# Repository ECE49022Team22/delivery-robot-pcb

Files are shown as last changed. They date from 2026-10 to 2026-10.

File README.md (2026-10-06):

# Delivery Robot PCB

KiCad design files for the ECE49022 Team 22 senior design delivery robot control board.

This repository is the shared workspace for the board schematic, PCB layout, project libraries and design documentation.

## System overview

The current schematic includes an STM32F091RC microcontroller core, programming/debug and UART headers, reset and boot circuitry, clock and decoupling components, test points, and power conversion from 12 V to 5 V and 3.3 V.

Motor-driver and IMU interfaces are part of the planned system and still need to be completed and reviewed in the board design.

## Getting started

1. Install KiCad 10 with its standard symbol and footprint libraries.
2. Clone this repository.
3. Open delivery_robot_1.kicad_pro in KiCad Manager.
4. Open delivery_robot_1.kicad_sch to view the complete schematic. Use the Schematic Hierarchy panel to navigate between sheets.

Custom symbol and footprint libraries are included and registered in the project library tables. Keep the directory structure intact so project-relative library paths resolve.

## Repository contents

| Path | Purpose |
| --- | --- |
| delivery_robot_1.kicad_pro | Active KiCad project settings |
| delivery_robot_1.kicad_sch | Main board schematic |
| LDO_3V3.kicad_sch | Hierarchical 3.3 V power supply sheet |
| libs/ | Custom buck converter symbols and footprints |
| LDO_KiCad/ | Reusable LDO example, libraries and footprint review |
| sym-lib-table, fp-lib-table | Project-specific library configuration |
| docs/ | Subsystem documentation and design notes |
| validation/ | Connectivity checks and reference netlist |
| system-ERC-report.txt | Saved electrical rules check results |
| system-netlist.xml | Exported system connectivity |
| system-preview/ | Rendered schematic sheets |
| received-project-settings/ | Archived initial settings; not the active project |

Power supply details are documented in [docs/power-supply.md](docs/power-supply.md). Earlier simulation notes are in [STM32-LDO-design.md](STM32-LDO-design.md).

Component-selection rationale is in [docs/passive-selection-review.md](docs/passive-selection-review.md), [docs/clock-selection.md](docs/clock-selection.md) and [docs/fuse-selection.md](docs/fuse-selection.md). The fuse selection includes both the PCB-mounted holder and its separately purchased insert.

## Design status

The project is in schematic development. No system PCB layout has been committed yet.

The saved ERC report from October 5, 2026 contains 7 errors and 55 warnings. Remaining work includes reviewing power connectivity and symbol definitions, completing peripheral interfaces, finalizing component values and footprints, and designing and checking the PCB layout.

Saved reports describe the checked revision. Regenerate them after relevant design changes.

## Team workflow

- Use the active delivery_robot_1 project for board work.
- Pull current changes before editing and coordinate ownership of schematic sheets and the PCB.
- Work on branches and review changes before merging.
- Save files in KiCad before committing. Include required project-local libraries with design changes.
- Run ERC after schematic changes and DRC after layout changes. Review outstanding findings before ordering boards.

Editing locks, local UI settings and automatic backups are excluded from Git. Edit the native KiCad sources directly; regenerating files from older scripts may overwrite manual changes.

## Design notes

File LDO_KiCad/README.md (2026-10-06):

# Reusable LDO schematic for KiCad

Created and verified with KiCad 10.0.6. All files are kept in this folder under Senior Design.

## Open and edit

Open this repository's LDO_KiCad/STM32_LDO.kicad_pro in KiCad Manager, then open STM32_LDO.kicad_sch and select LDO Power (page 2). The separately pinned original folder is not this repository copy.

The schematic was opened and saved through KiCad 10.0.6 on 2026-10-05 to apply its automatic format repair and conversion. ERC and the exported-netlist connection checks passed again after that save. Do not regenerate it from the original builder, which would overwrite these native editor saves.

Open **STM32_LDO.kicad_pro** in KiCad. Open its schematic, then enter the **LDO Power** hierarchical sheet. The circuit itself is **LDO_Power.kicad_sch**. The top sheet is an integration example with external-source PWR_FLAG symbols and an optional 3.3 V test point. The reusable child contains U1, R1/R2 and C1–C4 only.

The three sheet connections are:

| Sheet pin | Connect to |
|---|---|
| VIN_5V | Buck converter's regulated 5 V supply |
| VOUT_3V3 | STM32, IMU and other 3.3 V supply branches |
| GND | Common system ground |

No global power symbols are used in the child, so importing it will not silently merge rail names elsewhere. EN is tied to input for always-on operation. Both IN and OUT pins are wired; ground pin 4 and exposed pad 9 are grounded.

## Import into your teammates' system schematic

1. Copy `LDO_Power.kicad_sch`, `LDO_Power.kicad_sym` and the `LDO_Power.pretty` folder into their project folder. Keep their existing project and library tables.
2. In **Preferences → Manage Symbol Libraries → Project Specific Libraries**, add `LDO_Power.kicad_sym` with nickname `LDO_Power`. Use `${KIPRJMOD}/LDO_Power.kicad_sym` as its path.
3. In **Preferences → Manage Footprint Libraries → Project Specific Libraries**, add the `LDO_Power.pretty` folder with nickname `LDO_Power`. Use `${KIPRJMOD}/LDO_Power.pretty`.
4. In the system schematic editor, place a hierarchical sheet. Set its file to the copied `LDO_Power.kicad_sch` and keep the existing file contents. Give the sheet a name such as `LDO Power`.
5. Use **Import Sheet Pins** to bring in `VIN_5V`, `VOUT_3V3` and `GND`; wire them to the system rails.
6. Reannotate as needed to avoid duplicate U/R/C references. Run ERC on the complete system and update the PCB from that system schematic.

Do not replace your teammates' `sym-lib-table` or `fp-lib-table` with ours; add the two local entries instead. Symbols are embedded in the schematic for rendering, while the supplied library supports editing and consistency checks. The supplied footprint makes the regulator independent of a globally installed custom footprint library.

You can also copy/paste the components and wires into a flat system schematic, retaining the local libraries and replacing the hierarchical labels with that schematic's rail connections. The hierarchical-sheet method keeps this module easier to edit and reuse.

## Circuit and review status

- TPS7A8101DRBR, 5 V nominal input, 3.296 V nominal output, **1 A combined rail capacity**.
- R1 31.2 kΩ / 0.1%; R2 10 kΩ / 1%; C1 1 µF; C2 10 µF; C3/C4 470 nF.
- C1 Murata GRM188R71C105KA12D; C2 TDK C2012X7R1A106K125AC; C3/C4 Murata GRM188R71C474KA88D. Resistor procurement part numbers remain TBD; both resistor footprints are 0805. See ../docs/passive-selection-review.md for selection rationale and remaining electrical checks.
- Custom U1 symbol follows TI's pin-function table. Pad 9 represents the exposed ground pad. OUT pin 2 is typed passive to represent its intentional connection to OUT pin 1 without declaring a second independent power source.
- Local footprint was dimensionally verified and corrected against TI DRB0008A drawing 4218875/A: 0.65 mm pitch, 0.6 × 0.31 mm lead pads, 1.5 × 1.75 mm central exposed pad with four narrow extensions, and TI's central paste aperture plus four extensions. See `footprint-verification/VERIFICATION.md` for the full comparison and actual KiCad layer plots. Thermal vias must be added during PCB layout; confirm fabrication and assembly requirements before manufacturing.
- KiCad ERC passed with **0 errors and 0 warnings** on the parent + child project. The exported netlist was checked against the intended five circuit nets and all nine U1 pads.
- WEBENCH electrical simulations from the earlier design are documented in `../STM32-LDO-design.md`. This KiCad schematic does not contain a SPICE simulation model.
- This is a schematic module, not a routed PCB. MCU/IMU local decoupling belongs with those devices in the complete system. A 5 V encoder supply branches before the LDO.
- At 1 A, heat is roughly 1.7 W at 5 V input. Confirm actual combined load, thermal copper/vias and operating temperature before finalizing the PCB.

`preview/` contains KiCad-rendered previews. `ERC-report.txt` and `LDO-netlist.xml` record validation. Edit the supplied native KiCad sources directly.

Source: https://www.ti.com/lit/ds/symlink/tps7a8101.pdf (pin table and DRB0008A drawing 4218875/A).

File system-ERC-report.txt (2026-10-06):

ERC report (2026-10-05T21:03:44, Encoding UTF8)
Report includes: Errors, Warnings

***** Sheet /
[power_pin_not_driven]: Input Power pin not driven by any Output Power pins
    ; error
    @(48.26 mm, 167.64 mm): Symbol #PWR014 Pin 1 [Power input, Line]
[power_pin_not_driven]: Input Power pin not driven by any Output Power pins
    ; error
    @(81.28 mm, 36.83 mm): Symbol #PWR02 Hidden pin 1 [GND, Power input, Line]
[power_pin_not_driven]: Input Power pin not driven by any Output Power pins
    ; error
    @(90.17 mm, 140.97 mm): Symbol #PWR024 Hidden pin 1 [+5V, Power input, Line]
[power_pin_not_driven]: Input Power pin not driven by any Output Power pins
    ; error
    @(91.44 mm, 261.62 mm): Symbol #PWR020 Pin 1 [Power input, Line]
[power_pin_not_driven]: Input Power pin not driven by any Output Power pins
    ; error
    @(123.19 mm, 29.21 mm): Symbol #PWR03 Hidden pin 1 [+3.3VA, Power input, Line]
[power_pin_not_driven]: Input Power pin not driven by any Output Power pins
    ; error
    @(125.73 mm, 182.88 mm): Symbol #PWR032 Pin 1 [Power input, Line]
[power_pin_not_driven]: Input Power pin not driven by any Output Power pins
    ; error
    @(162.56 mm, 233.68 mm): Symbol #PWR023 Pin 1 [Power input, Line]
[lib_symbol_mismatch]: Symbol 'LED' doesn't match copy in library 'Device'
    ; warning
    @(36.83 mm, 143.51 mm): Symbol D3 [LED]
[lib_symbol_mismatch]: Symbol 'Crystal_GND24' doesn't match copy in library 'Device'
    ; warning
    @(43.18 mm, 93.98 mm): Symbol Y3 [Crystal_GND24]
[pin_to_pin]: Pins of type Unspecified and Passive are connected
    ; warning
    @(43.18 mm, 251.46 mm): Symbol U2 Pin 5 [VLDOIN, Unspecified, Line]
    @(30.48 mm, 251.46 mm): Symbol C9 Pin 1 [Passive, Line]
[pin_to_pin]: Pins of type Unspecified and Passive are connected
    ; warning
    @(43.18 mm, 266.70 mm): Symbol U2 Pin 12 [RT, Unspecified, Line]
    @(33.02 mm, 266.70 mm): Symbol R2 Pin 1 [Passive, Line]
[lib_symbol_mismatch]: Symbol 'TPS54202DDCR' doesn't match copy in library 'TPS54202DDCR'
    ; warning
    @(46.99 mm, 191.77 mm): Symbol U3 [TPS54202DDCR]
[pin_to_pin]: Pins of type Unspecified and Unspecified are connected
    ; warning
    @(86.36 mm, 231.14 mm): Symbol U2 Pin 8 [VOUT, Unspecified, Line]
    @(86.36 mm, 233.68 mm): Symbol U2 Pin 9 [VOUT, Unspecified, Line]
[pin_to_pin]: Pins of type Unspecified and Passive are connected
    ; warning
    @(86.36 mm, 233.68 mm): Symbol U2 Pin 9 [VOUT, Unspecified, Line]
    @(104.14 mm, 233.68 mm): Symbol R4 Pin 1 [Passive, Line]
[pin_to_pin]: Pins of type Unspecified and Passive are connected
    ; warning
    @(86.36 mm, 238.76 mm): Symbol U2 Pin 10 [FB, Unspecified, Line]
    @(104.14 mm, 241.30 mm): Symbol R4 Pin 2 [Passive, Line]
[pin_to_pin]: Pins of type Unspecified and Unspecified are connected
    ; warning
    @(86.36 mm, 243.84 mm): Symbol U2 Pin 3 [CBOOT, Unspecified, Line]
    @(86.36 mm, 248.92 mm): Symbol U2 Pin 4 [RBOOT, Unspecified, Line]
[isolated_pin_label]: Label connected to only one pin
    ; warning
    @(330.20 mm, 57.15 mm): Label 'PD2'
[isolated_pin_label]: Label connected to only one pin
    ; warning
    @(330.20 mm, 62.23 mm): Label 'PC0'
[isolated_pin_label]: Label connected to only one pin
    ; warning
    @(330.20 mm, 64.77 mm): Label 'PC1'
[isolated_pin_label]: Label connected to only one pin
    ; warning
    @(330.20 mm, 67.31 mm): Label 'PC2'
[isolated_pin_label]: Label connected to only one pin
    ; warning
    @(330.20 mm, 69.85 mm): Label 'PC3'
[isolated_pin_label]: Label connected to only one pin
    ; warning
    @(330.20 mm, 72.39 mm): Label 'PC4'
[isolated_pin_label]: Label connected to only one pin
    ; warning
    @(330.20 mm, 74.93 mm): Label 'PC5'
[isolated_pin_label]: Label connected to only one pin
    ; warning
    @(330.20 mm, 77.47 mm): Label 'PC6'
[isolated_pin_label]: Label connected to only one pin
    ; warning
    @(330.20 mm, 80.01 mm): Label 'PC7'
[isolated_pin_label]: Label connected to only one pin
    ; warning
    @(330.20 mm, 82.55 mm): Label 'PC8'
[isolated_pin_label]: Label connected to only one pin
    ; warning
    @(330.20 mm, 85.09 mm): Label 'PC9'
[isolated_pin_label]: Label connected to only one pin
    ; warning
    @(330.20 mm, 87.63 mm): Label 'PC10'
[isolated_pin_label]: Label connected to only one pin
    ; warning
    @(330.20 mm, 90.17 mm): Label 'PC11'
[isolated_pin_label]: Label connected to only one pin
    ; warning
    @(330.20 mm, 92.71 mm): Label 'PC12'
[isolated_pin_label]: Label connected to only one pin
    ; warning
    @(330.20 mm, 95.25 mm): Label 'USER_BTN'
[isolated_pin_label]: Label connected to only one pin
    ; warning
    @(330.20 mm, 97.79 mm): Label 'OSC32_IN'
[isolated_pin_label]: Label connected to only one pin
    ; warning
    @(330.20 mm, 100.33 mm): Label 'OSC32_OUT'
[lib_symbol_mismatch]: Symbol 'STM32F091RCTx' doesn't match copy in library 'MCU_ST_STM32F0'
    ; warning
    @(350.52 mm, 85.09 mm): Symbol U1 [STM32F091RCTx]
[isolated_pin_label]: Label connected to only one pin
    ; warning
    @(373.38 mm, 41.91 mm): Label 'PA0'
[isolated_pin_label]: Label connected to only one pin
    ; warning
    @(373.38 mm, 44.45 mm): Label 'PA1'
[isolated_pin_label]: Label connected to only one pin
    ; warning
    @(373.38 mm, 52.07 mm): Label 'PA4'
[isolated_pin_label]: Label connected to only one pin
    ; warning
    @(373.38 mm, 54.61 mm): Label 'LED_USER'
[isolated_pin_label]: Label connected to only one pin
    ; warning
    @(373.38 mm, 57.15 mm): Label 'PA6'
[isolated_pin_label]: Label connected to only one pin
    ; warning
    @(373.38 mm, 59.69 mm): Label 'PA7'
[isolated_pin_label]: Label connected to only one pin
    ; warning
    @(373.38 mm, 62.23 mm): Label 'PA8'
[isolated_pin_label]: Label connected to only one pin
    ; warning
    @(373.38 mm, 64.77 mm): Label 'PA9'
[isolated_pin_label]: Label connected to only one pin
    ; warning
    @(373.38 mm, 67.31 mm): Label 'PA10'
[isolated_pin_label]: Label connected to only one pin
    ; warning
    @(373.38 mm, 69.85 mm): Label 'PA11'
[isolated_pin_label]: Label connected to only one pin
    ; warning
    @(373.38 mm, 72.39 mm): Label 'PA12'
[isolated_pin_label]: Label connected to only one pin
    ; warning
    @(373.38 mm, 80.01 mm): Label 'PA15'
[isolated_pin_label]: Label connected to only one pin
    ; warning
    @(373.38 mm, 85.09 mm): Label 'PB0'
[isolated_pin_label]: Label connected to only one pin
    ; warning
    @(373.38 mm, 87.63 mm): Label 'PB1'
[isolated_pin_label]: Label connected to only one pin
    ; warning
    @(373.38 mm, 90.17 mm): Label 'PB2'
[isolated_pin_label]: Label connected to only one pin
    ; warning
    @(373.38 mm, 92.71 mm): Label 'SWO'
[isolated_pin_label]: Label connected to only one pin
    ; warning
    @(373.38 mm, 95.25 mm): Label 'PB4'
[isolated_pin_label]: Label connected to only one pin
    ; warning
    @(373.38 mm, 97.79 mm): Label 'PB5'
[isolated_pin_label]: Label connected to only one pin
    ; warning
    @(373.38 mm, 100.33 mm): Label 'PB6'
[isolated_pin_label]: Label connected to only one pin
    ; warning
    @(373.38 mm, 102.87 mm): Label 'PB7'
[isolated_pin_label]: Label connected to only one pin
    ; warning
    @(373.38 mm, 105.41 mm): Label 'PB8'
[isolated_pin_label]: Label connected to only one pin
    ; warning
    @(373.38 mm, 107.95 mm): Label 'PB9'
[isolated_pin_label]: Label connected to only one pin
    ; warning
    @(373.38 mm, 110.49 mm): Label 'PB10'
[isolated_pin_label]: Label connected to only one pin
    ; warning
    @(373.38 mm, 113.03 mm): Label 'PB11'
[isolated_pin_label]: Label connected to only one pin
    ; warning
    @(373.38 mm, 115.57 mm): Label 'PB12'
[isolated_pin_label]: Label connected to only one pin
    ; warning
    @(373.38 mm, 118.11 mm): Label 'PB13'
[isolated_pin_label]: Label connected to only one pin
    ; warning
    @(373.38 mm, 120.65 mm): Label 'PB14'
[isolated_pin_label]: Label connected to only one pin
    ; warning
    @(373.38 mm, 123.19 mm): Label 'PB15'

***** Sheet /LDO Power/

 ** ERC messages: 62  Errors 7  Warnings 55

 ** Ignored checks:
    - Global label only appears once in the schematic
    - Four connection points are joined together
    - SPICE model issue
    - Assigned footprint doesn't match footprint filters

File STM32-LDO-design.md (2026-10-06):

# 5 V to 3.3 V, 1 A LDO circuit

Prepared 2026-10-05. This supersedes STM32-LDO-preliminary.md. The circuit is a regulator design candidate with completed WEBENCH electrical simulations; PCB thermal performance and the full STM32 circuit remain to be verified.

## Circuit

See STM32-LDO-schematic.png. WEBENCH design 1 uses TPS7A8101DRBR, with 4.75–5.25 V input, 3.3 V / 1 A output target, and 30 °C ambient.

| Reference | Value / part | Connection |
|---|---|---|
| U1 | TI TPS7A8101DRBR, 8-pin SON with exposed pad | IN pins 7,8 to 5 V; OUT pins 1,2 to 3.3 V |
| C1 | 1 µF, 16 V X7R, Taiyo Yuden EMK107B7105KA-T | IN to GND, close to U1 |
| C2 | 10 µF, 10 V X7R, TDK C2012X7R1A106K125AC | OUT to GND, close to U1 |
| R1 | 31.2 kΩ, 0.1%, 0603 | OUT to FB pin 3 |
| R2 | 10.0 kΩ, 1% | FB pin 3 to GND |
| C3 | 470 nF ceramic | NR pin 6 to GND |
| C4 | 470 nF ceramic | OUT to FB, parallel with R1 |

Tie EN pin 5 to IN for always-enabled operation. Connect GND pin 4 and the exposed pad to ground. R1 is a custom WEBENCH value; a supplier part number still needs selection. Select actual C3/C4 parts and confirm voltage ratings before procurement.

Nominal divider voltage: 0.8 × (1 + 31.2 / 10.0) = 3.296 V. This is a nominal calculation, not a guaranteed tolerance. WEBENCH reports an output tolerance estimate of 3.87% with the selected components.

WEBENCH initially supplied a 28.7 kΩ top resistor that produced approximately 3.10 V, and an output capacitor derated below the regulator's required effective capacitance. Both were corrected before simulation. The selected C2 is estimated by WEBENCH at 8.8 µF after DC-bias derating; C1 at 0.9 µF. The regulator requires at least 4.7 µF effective output capacitance. Account for tolerance, bias and temperature in the final capacitor selection.

## Completed WEBENCH simulations

All three jobs completed successfully in the signed-in account:

| Job | Conditions | Observed result |
|---|---|---|
| Startup - 1 | Input 0→5 V, 10 µs delay and 10 µs rise; 3.3 Ω load | Output rises and settles near 3.3 V; a startup overshoot is visible |
| Load Transient - 2 | 5 V input; load 1→0.1→1 A; 1 µs edges; 120 ms pulse | Output remains near 3.3 V; displayed waveform spans approximately 3.294–3.296 V |
| Input Transient - 3 | 1 A load; input 4.75→5.25→4.75 V; 1 µs edges; 120 ms pulse | Output remains around 3.294 V in the model |

Saved screenshots: WEBENCH-startup.png and WEBENCH-load-transient.png. Waveform values are approximate readings from the displayed axes, not exported sample extrema. Simulation completion and idealized electrical results do not establish real hardware transient performance or thermal safety.

## Correct power architecture

12 V → Buck #2 → 5 V rail → this LDO → 3.3 V STM32 rail.

Any device needing 5 V must branch from the 5 V rail before the LDO. The motor driver retains its separate 12 V power feed. The motor's A/B feedback lines suggest the separate 5 V connection may power an encoder; confirm this with the motor documentation. A 5→3.3 V LDO cannot provide a 5 V output.

STM32 control outputs command a motor driver; motor winding current flows through the driver, not the MCU power rail. Treat 1 A here as requested rail capacity, not established STM32 consumption. If the LDO actually supplies 1 A and other loads share the 5 V rail, the proposed 5 V / 1 A buck has insufficient current margin. Size it for the combined loads plus regulator ground current and margin.

## PCB and MCU integration

At 1 A, dissipation is approximately (5−3.3)×1 = 1.7 W; at 5.25 V it is about 1.95 W, excluding ground current. Using the datasheet's 47.8 °C/W junction-to-ambient value gives a rough junction estimate of 123 °C at 30 °C ambient and 1.95 W, close to the 125 °C recommended maximum. This is a reference-board calculation, not a thermal simulation or prediction for your layout. Use the exposed pad, adequate ground copper and thermal vias, then verify temperature on the final board. A direct 12→3.3 V buck is worth considering if sustained 1 A is actually required.

Place the input/output capacitors close to U1; keep feedback routing short and away from motor switching currents. This schematic covers the regulator only. Add MCU VDD/VDDA decoupling, VCAP components where required, reset and boot circuitry using the exact STM32 datasheet. Confirm 3.3 V motor-driver logic compatibility and whether encoder outputs need level shifting. A Nucleo model is not needed for this generic regulator design; it is needed only to identify its exact onboard circuitry or MCU-specific requirements.

## Sources

## BNO085 IMU addition

The IMU is a parallel load on the supply, not powered through an STM32 GPIO. For a bare BNO085, 3.3 V can supply both VDD (recommended 2.4–3.6 V) and VDDIO (1.7–3.6 V), with the manufacturer's local decoupling. VDD must reach its specified level before or at the same time as VDDIO. For the Adafruit breakout, connect the shared 3.3 V rail to VIN and common ground to GND, following Adafruit's recommendation to match VIN to MCU logic voltage. Its 3Vo pin is an output; do not connect it to the external LDO output.

CEVA revision 1.17, section 6.10, Figure 6-17 gives typical BNO085 currents measured with VDDIO = 3 V and VDD = 3.3 V using SPI. Summing the two rail currents gives approximately 11.0 mA at 100 Hz fusion, 12.84 mA at 200 Hz, 14.4 mA at 400 Hz, and 14.64 mA at 1 kHz gyro rotation vector. These are typical sample configurations, not guaranteed peaks or measurements of the Adafruit board. Allocate 30 mA provisionally for the IMU branch, then measure the actual breakout, operating mode and startup peaks. This allowance is engineering margin, not a datasheet maximum.

The total rail budget is I_STM32 + I_IMU + I_other_3V3. The existing 1 A regulator is sufficient only if that combined load fits within its rating with margin and passes thermal checks. If the STM32 really requires 1 A by itself, adding the IMU exceeds the selected regulator's capacity; do not simply run another simulation above its 1 A rating. The earlier 1 A simulations cover the combined rail only up to 1 A and did not model IMU startup independently.

Sources for this addition:
- CEVA: https://www.ceva-ip.com/wp-content/uploads/BNO080_085-Datasheet.pdf
- Adafruit: https://learn.adafruit.com/adafruit-9-dof-orientation-imu-fusion-breakout-bno085/pinouts

## Regulator sources

- TI TPS7A8101 datasheet: https://www.ti.com/lit/ds/symlink/tps7a8101.pdf
- TI product page: https://www.ti.com/product/TPS7A8101
- TDK capacitor: https://product.tdk.com/en/search/capacitor/ceramic/mlcc/info?part_no=C2012X7R1A106K125AC
- Signed-in WEBENCH design: https://webench.ti.com/power-designer/switching-regulator/simulate/1

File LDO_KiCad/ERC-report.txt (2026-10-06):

ERC report (2026-10-05T20:21:00, Encoding UTF8)
Report includes: Errors, Warnings

***** Sheet /

***** Sheet /LDO Power/

 ** ERC messages: 0  Errors 0  Warnings 0

 ** Ignored checks:
    - Global label only appears once in the schematic
    - Four connection points are joined together
    - SPICE model issue
    - Assigned footprint doesn't match footprint filters

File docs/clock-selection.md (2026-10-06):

# STM32 HSE crystal and load-capacitor selection

Selected 2026-10-05 for U1, STM32F091RCTx. Y3/C5/C6 are marked DNP: their selected parts and PCB footprints are retained, but initial assembly leaves them unpopulated. Firmware must use an internal clock while these parts are DNP. Populate all three together before enabling crystal HSE mode. No wires or pin assignments change. This is the high-speed system-clock crystal, not a 32.768 kHz RTC crystal or a powered clock oscillator.

| Reference | Purchasing part | Specification | Footprint |
|---|---|---|---|
| Y3 | Abracon ABM3B-8.000MHZ-B2-T | 8 MHz fundamental, CL 18 pF, ESR max 200 ohm, shunt C0 max 7 pF; +/-20 ppm initial tolerance, +/-50 ppm stability, -20 to +70 C | Crystal:Crystal_SMD_Abracon_ABM3B-4Pin_5.0x3.2mm |
| C5, C6 | Murata GRM1885C1H160JA01D | 16 pF, +/-5%, 50 V, C0G/NP0, 0603 (1.6 x 0.8 mm), -55 to +125 C | project_footprints:C_Murata_GRM1885C1H160JA01 |

## Frequency and loading

[STM32F091xB/xC datasheet, DocID026284 Rev 4](https://www.st.com/resource/en/datasheet/stm32f091rc.pdf), section 6.3.7, Table 39 and accompanying text, page 69, allows a 4-32 MHz HSE crystal and specifies 10 mA/V minimum startup transconductance. Eight MHz supports a 48 MHz system clock using HSE /1 and PLL x6. Firmware must select crystal HSE mode (HSE ON, not external-clock BYPASS), use HSE_VALUE=8000000 and configure the appropriate PLL. Existing team firmware was not provided or verified. The crystal temperature option covers the team's previously stated -10 to +40 C range.

[ST AN2867 oscillator design guide](https://www.st.com/resource/en/application_note/cd00221665-oscillator-design-guide-for-stm8af-al-s-stm32-mcus-and-mpus-stmicroelectronics.pdf), sections 3.3-3.5, explains load capacitance and startup/drive checks. For equal capacitors, CL = C/2 + Cs. The MCU datasheet suggests **10 pF as a rough combined pin/board capacitance estimate**, so C = 2 x (18 - 10) = **16 pF each**. This meets its typical 5-20 pF external-capacitor recommendation. Sixteen pF is an actual standard purchasing value; it is not a placeholder or a required 0805 resistor package. C0G avoids the capacitance drift of high-permittivity dielectrics; 50 V is the available part rating, not the oscillator voltage.

The 10 pF estimate is not a measurement or guaranteed parasitic capacitance. If actual Cs is 5 pF, this pair would load the crystal at approximately 13 pF rather than 18 pF, shifting frequency. Final capacitor values must follow the completed PCB parasitics and measured clock frequency. The 7 pF crystal shunt capacitance C0 belongs in the startup calculation below; do not add it again as Cs in the load calculation.

## Startup screening and drive limit

Using Abracon's maximum ESR and C0 from [ABM3B Rev U, pages 1-2](https://abracon.com/Resonators/abm3b.pdf), the AN2867 screening equation gives:

`gmcrit = 4 x 200 x (2*pi*8e6)^2 x ((7+18)*1e-12)^2 = 1.263 mA/V`

`gain margin = gm_min/gmcrit = 10/1.263 = 7.92`

This exceeds ST's recommended minimum margin of 5 at the specified crystal load. It screens compatibility; it does not replace startup measurements on the assembled board. Abracon specifies 10 uW typical / 100 uW maximum drive. Crystal power cannot be established from the schematic alone. Follow AN2867 section 3.5 to measure drive and section 3.8 for practical startup-margin verification; if drive exceeds 100 uW, introduce/tune a series resistor on OSC_OUT and repeat the startup-margin check. There is currently no series-resistor footprint in this circuit. Reserve space during layout for that possible adjustment, and do not release the clock network for production without the drive check.

## Footprint justification

**Y3:** Abracon page 3 gives a 5.00 +/-0.10 x 3.20 +/-0.10 mm body, maximum height 1.10 mm. Its recommended lands are four 1.80 x 1.20 mm pads with center pitches 4.00 mm horizontally and 2.40 mm vertically. The installed KiCad ABM3B footprint has these exact dimensions: centers (+/-2.00, +/-1.20) mm. Top-view pin numbering matches the manufacturer: 1 lower left, 2 lower right, 3 upper right, 4 upper left; pins 1/3 are crystal terminals and 2/4 are ground. The existing symbol and nets match this mapping. We use the existing standard footprint; no custom crystal symbol or footprint is required.

**C5/C6:** [Murata GRM1885C1H160JA01-01A reference sheet](https://search.murata.co.jp/Ceramy/image/img/A01X/G101/ENG/GRM1885C1H160JA01-01A.pdf), page 2, specifies the body as 1.6 +/-0.1 x 0.8 +/-0.1 mm. Page 27, Table 2, GRM18 within +/-0.10 mm, recommends reflow gap a=0.6-0.8, pad length b=0.6-0.7, pad width c=0.6-0.8 mm. The project-local pattern chooses a=0.70, b=0.65, c=0.70: two **0.65 x 0.70 mm pads**, centers +/-0.675 mm, giving a **0.70 mm inner gap**. Its courtyard encloses maximum body and pad extents with at least 0.25 mm clearance. This pattern is derived from Murata's drawing, not imported vendor CAD. The installed generic 0603 has 0.90 x 0.95 mm pads and was not used because those dimensions exceed this reflow recommendation. Assembly process review is still required; a hand-soldering pattern would need a separate assessment.

## Layout and verification

Place Y3 and both capacitors immediately next to PF0/OSC_IN and PF1/OSC_OUT; use short traces and short capacitor ground returns. Ground Y3 pins 2/4. Keep switching nodes, inductors, motor PWM and fast signals away from the oscillator, including adjacent layers. Follow AN2867 layout guidance and account for ground shielding in the final parasitic estimate. Measure clock frequency via an MCU clock-output pin where possible; directly probing crystal pins adds capacitance and can disturb oscillation. Verify startup over the intended supply/temperature range and across boards.

KiCad CLI netlist export and pcbnew footprint measurements confirm the implemented values, pad numbers, pad dimensions and unchanged component-pin net sets. Only Y3/C5/C6 have new nominal values/footprint assignments; their original DNP flags are retained. Before/after ERC reports have identical findings: 5 existing errors and 56 existing warnings, with no new findings. Existing KiCad field-order/formatting edits were preserved. These checks do not simulate crystal startup or certify drive level. F1 was subsequently selected; see [fuse-selection.md](fuse-selection.md). J2 remains the system's missing footprint selection.

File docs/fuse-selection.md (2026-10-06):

# F1 battery-input fuse and holder

Selected 2026-10-05. The user confirmed that the requested "F2" means the existing F1, between J2 pin 1 and the +12V net feeding both buck converters. F1 is populated. Connectivity and all other part selections are unchanged. This branch supplies the PCB/Pi electronics; it does not include the separately wired 12 V motor-driver power branch.

## Purchasing and assembly

| F1 assembly item | Manufacturer / part number | Quantity | Role |
|---|---|---|---|
| Holder | Keystone Electronics **3568** | 1 | Through-hole MINI blade-fuse holder soldered to the PCB |
| Fuse | Littelfuse **029707.5L** | 1 | Replaceable 7.5 A, 32 VDC, silver-plated MINI fuse inserted into the holder |

The schematic's main Manufacturer/MPN/Datasheet fields describe the **PCB-mounted holder**, since that is what its footprint represents. FuseManufacturer, FuseMPN and FuseDatasheet identify the separately purchased insert. **Order both items.** A BOM exporter using only the main MPN column will omit the fuse; expand F1 into these two purchasing rows. `fuse-selection.json` explicitly records both quantities. The .L suffix is Littelfuse's 50-piece package designation, not a different electrical rating; distributor single-piece purchases are acceptable when the actual manufacturer part and ratings match.

Assigned footprint: `Fuse:Fuseholder_Blade_Mini_Keystone_3568`. No custom symbol or footprint is required. Standard MINI and low-profile MINI/ATO are different mechanical formats; use the specified standard MINI fuse.

## Electrical sizing

The existing outputs are 5 V / 6 A and 5 V / 2 A, totaling **40 W** at their full rated loads. The LDO is already supplied from the 2 A branch; its load must not be counted again. Using the supplied battery's 10.8 V minimum normal voltage and an **assumed 85% combined conversion efficiency**:

`Iinput = (5*6 + 5*2) / (10.8*0.85) = 4.36 A`

This is a sizing estimate, not a measured maximum or guaranteed converter efficiency. At 14.6 V with the same efficiency, it is 3.22 A. Quiescent current, actual thermal efficiency, fuse/connector/wire voltage drops, load peaks and startup must be included in the final measurements. No additional direct 12 V loads are included; revisit the selection if such loads are added to the fused net.

[Littelfuse MINI 32 V datasheet, revised 2024-09-27](https://www.littelfuse.com/assetdocs/littelfuse-datasheet-297-mini32v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), page 3, provides a typical allowed-current table with a 20% temperature security margin. At 40 C, its 5 A fuse allows 4.0 A, while its 7.5 A fuse allows 6.0 A. Thus **7.5 A is the lowest standard option in this series above the estimated 4.36 A continuous load at the team's 40 C ambient limit**. The allowance decreases to 5.5 A at 60 C and 5.1 A at 80 C. Use the actual temperature near the fuse, including enclosure and converter heating. These are application-dependent typical recommendations, not guaranteed hold-current limits. Do not apply another generic derating factor to this already derated table without identifying why it is needed.

The same datasheet, pages 1-2, specifies **32 VDC** operation and **1000 A interruption at 32 VDC**, exceeding the 14.6 V normal battery maximum. The 7.5 A insert has 10.85 milliohm typical cold resistance, giving approximately 0.21 W cold-element loss at 4.36 A, excluding holder contact loss and hot-resistance increase. [Keystone's 3568 product specification](https://www.keyelco.com/product.cfm/product_id/306) lists a 30 A holder and explicitly names Littelfuse 297/997 compatibility. Holder current capability therefore exceeds the selected fuse and expected continuous current. The holder's current rating does not establish the fuse assembly's fault-interruption capacity.

The fuse remains a **protection candidate pending coordination with the final conductors and source**. Battery BMS limits of 50 A continuous and 150 A briefly do not bound prospective short-circuit current. Confirm the battery/source and wiring cannot deliver a fault exceeding the fuse's 1000 A DC interrupt rating, or select protection with sufficient interruption capacity. The seller battery PDF does not provide the needed short-circuit/clearing specification.

## Verified mechanical footprint

[Keystone drawing 3568, revision E, 2023-05-17](https://www.keyelco.com/product-pdf.cfm?p=306) gives four holes on **9.92 x 3.40 mm** centers and **1.60 mm minimum hole diameter**. The manufacturer drawing was inspected from this [distributor-hosted copy](https://static.maritex.eu/file/display/oKaI5t3ooLkeEAjZJtX48nclaUUGNRNT/KEYSTONE-3568.pdf) when direct download was blocked. The drawing shows a 16.00 x 6.73 mm holder body, 7.37 mm above-board height and 2.79 mm lead extension; its dimensions are unrelated to an 0805 resistor package.

pcbnew loads the installed KiCad footprint and confirms:

- Terminal 1: pads at (0,0) and (0,3.40) mm.
- Terminal 2: pads at (9.92,0) and (9.92,3.40) mm.
- All four pads: **1.78 mm plated-hole drill**, **2.78 mm copper diameter**. The holes exceed the manufacturer's 1.60 mm minimum; annular-ring width is 0.50 mm nominal. Confirm the PCB fabricator's finished-hole/plating tolerances.
- Both holes of each physical contact have the same pad number. This correctly maps the four mechanical leads to the two electrical fuse terminals. Route adequate copper to both pads of each terminal.

The 297 insert's 2.8 x 0.8 mm blades match the holder family specified by Keystone. The fuse goes into the holder; it is not soldered directly into these four PCB holes. Reserve clearance above the installed fuse and room to grip/remove it; the holder's 7.37 mm height alone is not the assembled height. Position it near J2 with appropriately rated input copper and accessible service space.

## Protection boundaries and remaining verification

A 7.5 A fuse does **not** open immediately at 7.5 A. The datasheet page 3 opening-time limits include 0.15-5 seconds at 200% rating (15 A) and 0.03-0.1 seconds at 600% (45 A). Verify that J2, wires, copper, vias and contacts tolerate the applicable overload/clearing energy; their final geometry/rating is not established yet. Use the time-current curve and measured input startup pulse to check nuisance blowing. The 82 A2s typical pre-arcing I2t is not a guaranteed total-clearing-energy limit and cannot alone certify PCB protection.

F1 provides branch overcurrent protection; it is not a TVS, reverse-polarity protector or a guarantee against semiconductor damage. The PCB fuse does not protect the battery cable segment before F1; protection near the battery must cover that segment. Motor-branch fusing and regenerative transient suppression require their own design. Do not size this PCB fuse to the battery's 50 A BMS rating.

KiCad export verifies that only F1's purchasing fields/value/footprint changed and all component-pin net sets are identical. Clock Y3/C5/C6 remain DNP. J2 remains the sole missing footprint. Physical fit has been checked against the holder drawing; inrush, thermal and fault-current coordination have not been measured or simulated.

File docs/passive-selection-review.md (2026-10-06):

# Capacitor and inductor selections

Selected on 2026-10-05 for the existing 5 V buck rails and 3.3 V LDO. The user supplied a 10.8-14.6 V normal battery range for the 4S LiFePO4 pack. This range is user-provided, not independently verified from a battery manufacturer datasheet. Motor transients are not bounded by the charge voltage. These selections establish component packages and purchasing candidates; they do not constitute a completed transient, loop-stability, thermal, or input-protection validation.

The resistor-only 0805 requirement is preserved. Capacitor values and wiring are unchanged. L1 changes from 10 uH to 15 uH for ripple-current margin. Schematic fields contain Manufacturer, MPN, Datasheet and (for root-sheet parts) Specification. `passive-selections.json` records the selections in machine-readable form.

## Parts and packages

| References | Selected part | Electrical specification | KiCad footprint |
|---|---|---|---|
| C7, C8 | Murata GRM32ER71H106KA12L | 10 uF, 50 V, X7R, 10% | Capacitor_SMD:C_1210_3225Metric |
| C9, C24 | Murata GRM188R71C105KA12D | 1 uF, 16 V, X7R, 10% | Capacitor_SMD:C_0603_1608Metric |
| C10 | Murata GRM1885C1H8R2DA01D | 8.2 pF, 50 V, C0G, +/-0.5 pF | Capacitor_SMD:C_0603_1608Metric |
| C11, C12, C17 | Murata GRM32ER71A476ME15L | 47 uF, 10 V, X7R, 20% | project_footprints:C_Murata_GRM32ER71A476ME15 |
| C14 | TDK C5750X7R1H226M250KB | 22 uF, 50 V, X7R, 20% | project_footprints:C_TDK_C5750X7R1H226M250KB |
| C15 | TDK C1608X7R1H104K080AA | 100 nF, 50 V, X7R, 10% | Capacitor_SMD:C_0603_1608Metric |
| C16 | Murata GRM1885C1H680JA01D | 68 pF, 50 V, C0G, 5% | Capacitor_SMD:C_0603_1608Metric |
| C25, retained | TDK C2012X7R1A106K125AC | 10 uF, 10 V, X7R, 10% | Capacitor_SMD:C_0805_2012Metric |
| C26, C27 | Murata GRM188R71C474KA88D | 470 nF, 16 V, X7R, 10% | Capacitor_SMD:C_0603_1608Metric |
| L1 | Coilcraft XAL6060-153MEC | 15 uH, 20%, shielded power inductor | Inductor_SMD:L_Coilcraft_XAL6060-XXX |

The reusable LDO example uses the same C24/C26/C27 parts as C1/C3/C4. C24 replaces the previously specified Taiyo Yuden ordering number; capacitance, voltage rating and package are preserved.

## Electrical rationale

[TI TPSM63606, SLVSGB4B Rev. B](https://www.ti.com/lit/ds/symlink/tpsm63606.pdf), sections 8.3.3/8.3.4 and Tables 8-1/8-2/8-3, pages 16-17: the input requires two 10 uF ceramics in 1206 or 1210. C7/C8 use the exact Murata 50 V, 1210 part listed in Table 8-2. At 5 V output, Table 8-1 specifies 30 uF effective output capacitance. C11/C12 use a Table 8-3 47 uF X7R candidate in 1210. Section 9.2.1.2.5, page 24, describes two 47 uF ceramics with approximately 52 uF effective at 25 C and 38 uF at -40 C. These are example estimates, not guaranteed limits for every production part. Use the stricter table requirement rather than the conflicting 25 uF prose value. C9 remains a small bias bypass; C10 uses C0G for stable feedforward capacitance. The existing C10 value is retained; package selection does not verify phase margin.

[TI TPS54202, SLVSD26C Rev. C](https://www.ti.com/lit/gpn/tps54202), section 7.2.3.5, pages 15-17, and Table 7-2: 15 uH is the 5 V example selection. With 2 A output, 5 V output, 390 kHz minimum oscillator frequency and 12 uH minimum inductance (15 uH minus 20%), estimated ripple is 0.703 A peak-to-peak at 14.6 V, giving 2.352 A peak and 2.010 A RMS. At the IC's 28 V operating limit the estimate is 2.439 A peak, versus 2.658 A for a 10 uH part at its -20% tolerance. The 15 uH selection improves margin against the 2.5 A minimum high-side current-limit threshold. These calculations omit further inductance reduction under DC current and temperature; confirm the operating curve and actual converter behavior.

[Coilcraft XAL60xx, Document 887 Rev. 02/25/26](https://www.coilcraft.com/getmedia/ea51f14b-7f32-4dc6-8dfe-d4b70549040f/xal60xx.pdf), page 1: XAL6060-153 has 43.75 milliohm maximum DCR, 5.8 A typical 30%-drop saturation current and 4.5/6.0 A thermal reference currents for 20/40 C rise at 25 C ambient. This provides current margin including the IC's 3.9/4.3 A maximum high/low-side thresholds. Normal 2 A copper loss is about 0.18 W using maximum DCR; temperature derating and total AC loss still require checking in the PCB. Its size is chosen for these ratings, not to force an 0805 inductor.

C14 retains 22 uF with a 50 V X7R part to provide voltage headroom and room for a substantial ceramic capacitor on the battery input. Its 2220 body is larger than a 25 V candidate; this is a conservative selection rather than a minimum-area optimization. C15's 50 V rating exceeds the approximately 5 V bootstrap-capacitor differential; C16 uses C0G to retain its small feedforward value. C17 preserves the existing single 47 uF output capacitor with a 1210 purchasing candidate. **The single-capacitor C17 network still needs a load-transient and effective-capacitance check:** TI's 1.5 A, 5% example requires 24 uF at 500 kHz; a 2 A step at 390 kHz requires about 41 uF effective for a 0.25 V droop target. A nominal 47 uF ceramic cannot be assumed to meet that after bias, tolerance and temperature. Add capacitance if the final transient requirement demands it; no additional capacitor or simulated transient result is implied by this commit.

[TI TPS7A8101](https://www.ti.com/lit/gpn/tps7a8101) requires adequate effective output capacitance for stability (4.7 uF minimum). The existing C25 10 uF 0805 selection is retained; its [TDK specification and characteristic data](https://product.tdk.com/en/search/capacitor/ceramic/mlcc/info?part_no=C2012X7R1A106K125AC) must be used when checking DC-bias/tolerance/temperature margin. C24 and C26/C27 are 16 V X7R parts for the 5 V input and low-voltage noise/bypass nodes. Replacing part-number placeholders does not change those functions.

## Mechanical sources and checks

- [Murata 10 uF, 50 V reference sheet](https://search.murata.co.jp/Ceramy/image/img/A01X/G101/ENG/GRM32ER71H106KA12-04A.pdf): 3.2 x 2.5 mm body, 1210.
- [Murata 47 uF, 10 V reference sheet](https://search.murata.co.jp/Ceramy/image/img/A01X/G101/ENG/GRM32ER71A476ME15-04CA.pdf): 3225 metric / 1210.
- [Murata 1 uF reference sheet](https://search.murata.co.jp/Ceramy/image/img/A01X/G101/ENG/GRM188R71C105KA12-01.pdf): 1.6 x 0.8 mm, 0603.
- [Murata 8.2 pF reference sheet](https://search.murata.co.jp/Ceramy/image/img/A01X/G101/ENG/GRM1885C1H8R2DA01-01A.pdf) and [68 pF reference sheet](https://search.murata.co.jp/Ceramy/image/img/A01X/G101/ENG/GRM1885C1H680JA01-01A.pdf): 0603, C0G.
- [TDK C14 specifications](https://product.tdk.com/en/search/capacitor/ceramic/mlcc/info?part_no=C5750X7R1H226M250KB): body 5.70 +/-0.40 x 5.00 +/-0.40 mm, height 2.50 +/-0.30 mm; recommended PA 4.10-4.80, PB 1.20-1.40, PC 4.00-5.00 mm. The supplied project-local footprint uses 4.2 mm inner gap, 1.3 mm pad width, 5.0 mm pad height and a courtyard covering maximum body dimensions. The generic KiCad 2220 footprint's 3.3 mm inner gap was not used. This footprint is derived from TDK dimensions, not imported from TDK. Verify assembly tolerances with the board assembler.
- [TDK C15 specifications](https://product.tdk.com/en/search/capacitor/ceramic/mlcc/info?part_no=C1608X7R1H104K080AA): 0603, 100 nF, 50 V.
- [Murata 470 nF reference sheet](https://search.murata.co.jp/Ceramy/image/img/A01X/G101/ENG/GRM188R71C474KA88-01A.pdf): 0603, 16 V X7R.
- Coilcraft Document 887, page 4: nominal body 6.56 x 6.36 mm, maximum height 6.1 mm; recommended two 1.43 x 5.50 mm pads on 4.04 mm centers. The installed KiCad XAL6060 footprint exactly matches those pad sizes and center spacing. Place the marked winding start toward the SW node as recommended for EMI; the inductor is electrically nonpolarized.

Existing MCU bypass-capacitor footprints are retained; this power-passive selection does not assign their purchasing part numbers. Y3 and C5/C6 were subsequently selected together; see [clock-selection.md](clock-selection.md) for the 8 MHz crystal, 16 pF C0G pair and manufacturer land-pattern checks. F1 subsequently received a replaceable MINI fuse/holder selection; see [fuse-selection.md](fuse-selection.md) for both purchasing parts, electrical assumptions and protection checks. J2 remains the outstanding footprint choice. Input transient suppression, input bulk damping, capacitor RMS heating, final loop stability and PCB thermal/layout review remain separate work.

## Verification

KiCad 10.0.6 successfully exported the edited system schematic. Before/after component-pin net sets are identical. Capacitances and all unrelated values are unchanged; L1 is the sole nominal-value change. All selected footprint files exist. pcbnew loads the C14 footprint and confirms both pads against the TDK ranges; it also confirms the L1 pads against Coilcraft's drawing. Full-system ERC has existing findings and is not a manufacturing sign-off. No converter simulations were rerun in this task.

## Murata output-capacitor land-pattern verification

C11/C12/C17 use a project-local footprint derived from the selected part's reference sheet GRM32ER71A476ME15-04CA, page 27, Table 2 (Reflow Soldering). For GRM32, Murata gives a (inner gap) = 2.0-2.4 mm, b (pad length) = 1.0-1.2 mm, c (pad width) = 1.8-2.3 mm. We choose the midpoint of each range: 2.2 mm gap and two 1.1 x 2.1 mm pads, on 3.3 mm centers. The generic KiCad 1210 pattern had a 1.8 mm gap and 2.7 mm pad width, outside those recommendations, although its IPC nominal package designation was correct. The new courtyard includes the maximum body dimensions (3.5 x 2.7 mm) and copper pad extents with 0.25 mm clearance. Pads 1/2 are nonpolarized and retain their net assignments. pcbnew loading and measured pad dimensions verify the implementation; exported system netlists confirm no component value or connectivity changes. This verifies physical land geometry, not C17 effective capacitance or converter transient response. Other capacitor footprints have not been certified against every manufacturer reflow range by this correction.

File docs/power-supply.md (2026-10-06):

# Power supply integration

The root schematic contains two separate buck converter outputs:
- TPS54202: +5V, 2A.
- TPSM63606: +5V, 6A.

The TPS7A8101 LDO in LDO_3V3.kicad_sch is supplied by the +5V, 2A rail. Its +3V3 output supplies the STM32 digital power pins, associated decoupling, programming-header supply, and the FB2 input feeding the separate +3.3VA analog rail. The two buck outputs are separate nets.

The LDO uses U4, R8/R9 and C24-C27. The former VDD power symbols use +3V3 to connect these loads to the regulator. The 1 A rating is combined rail capacity, not measured MCU current consumption. Full-load dissipation is approximately 1.7 W at 5 V input; PCB thermal copper and vias remain to be designed.

See ../LDO_KiCad/README.md for component values, the standalone example and reuse instructions. See ../LDO_KiCad/footprint-verification/VERIFICATION.md for the LDO footprint review. Existing buck footprints resolve to supplied files, but their physical dimensions have not been reviewed here.

The project-local symbol and footprint tables include all supplied custom power components. They use paths relative to the project directory.

All system resistors R1-R9 use Resistor_SMD:R_0805_2012Metric to meet the team's 0805 package requirement. The reusable LDO example uses the same resistor footprint. Resistance values and tolerances are unchanged; select purchasing parts in 0805 with suitable power and working-voltage ratings. Footprint assignment alone does not establish those ratings.

See [passive-selection-review.md](passive-selection-review.md) for the capacitor/inductor purchasing candidates, manufacturer dimensions, L1's 15 uH selection, and outstanding transient checks.

## Integration validation

validation/verify_integration.py checks the KiCad-exported system netlist against validation/before-integration.xml. It verifies the five LDO nets, all nine U4 pads, MCU supply connections, analog filter input, unique component references, and preservation of the original circuit except the intended VDD/+3V3 merge.

Run it from the repository with a Python installation after exporting system-netlist.xml:

    kicad-cli sch export netlist --format kicadxml -o system-netlist.xml delivery_robot_1.kicad_sch
    python validation/verify_integration.py

This check covers power integration. Run full-system ERC and, once a PCB exists, DRC separately.

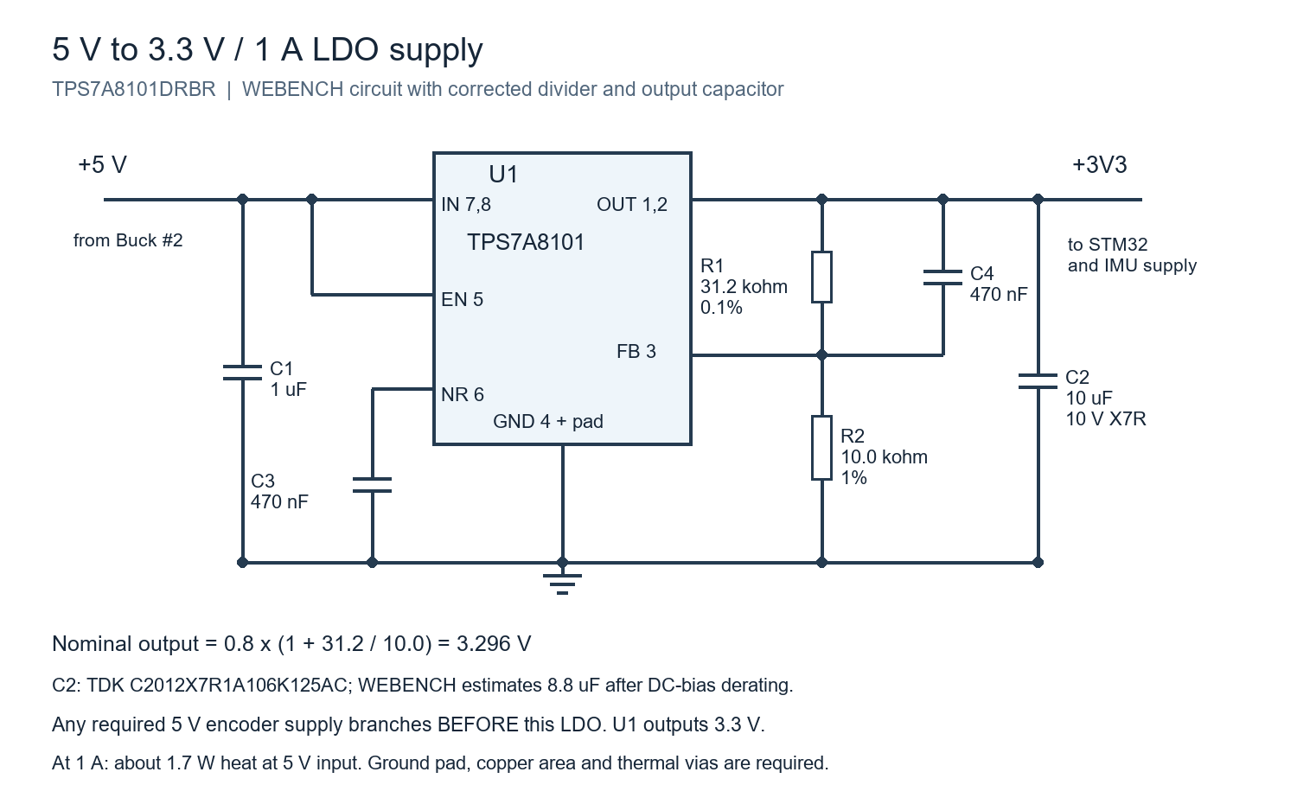
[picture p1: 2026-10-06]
STM32-LDO-schematic.png

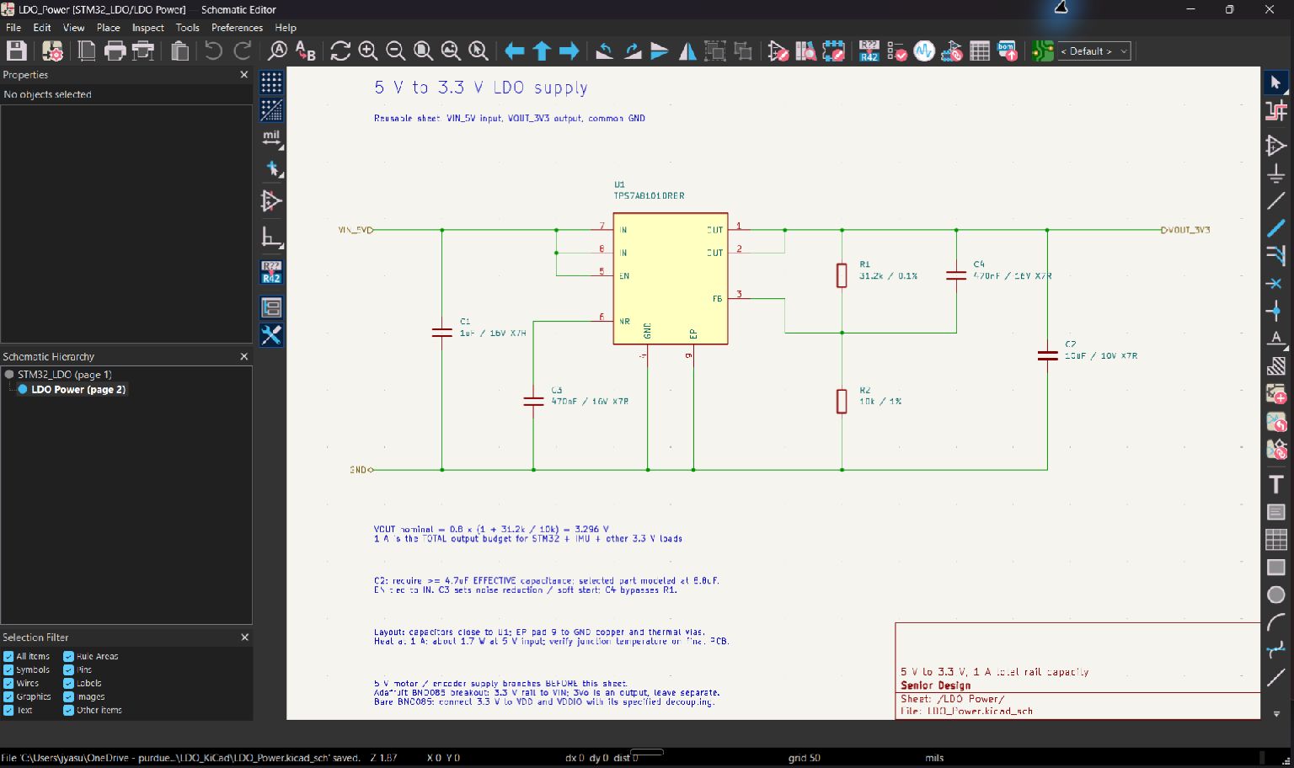
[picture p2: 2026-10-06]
LDO_KiCad/preview/KiCad-open-schematic.png

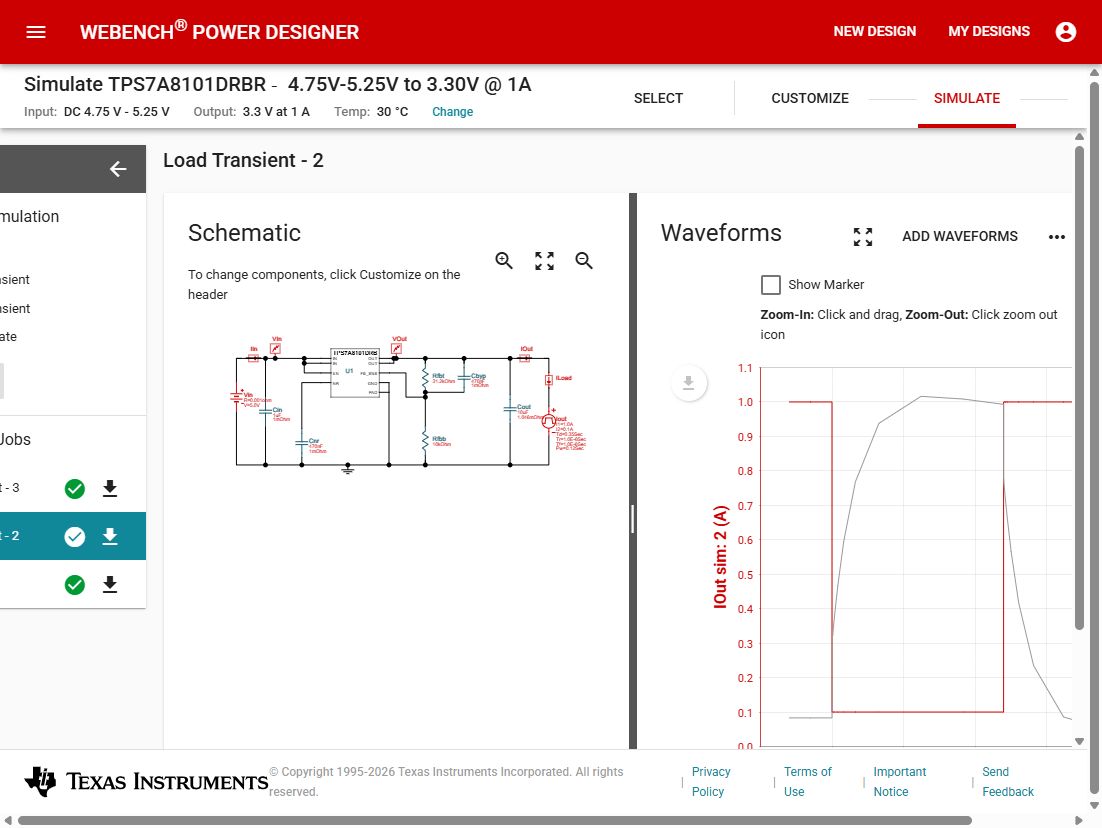
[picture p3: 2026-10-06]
WEBENCH-load-transient.png

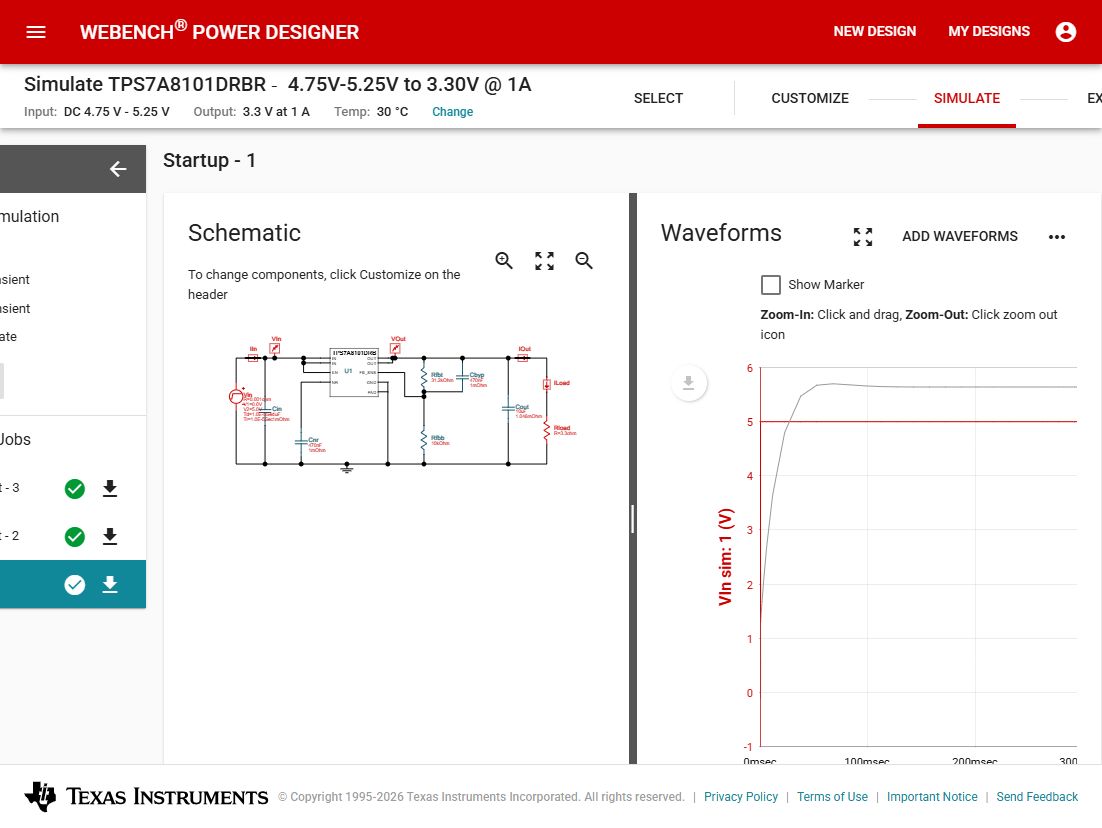
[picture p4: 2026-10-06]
WEBENCH-startup.png

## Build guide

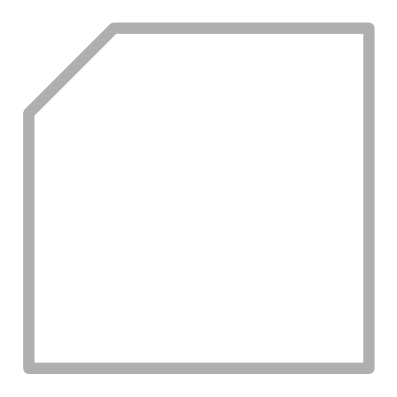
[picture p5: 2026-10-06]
LDO_KiCad/footprint-verification/fabrication.png

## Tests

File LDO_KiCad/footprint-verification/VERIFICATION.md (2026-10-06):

# TPS7A8101DRBR footprint verification

Reviewed 2026-10-05 with KiCad 10.0.6. Result: the corrected library footprint matches the nominal geometry of TI's DRB0008A recommended land pattern and stencil example. This is dimensional verification, not approval of a finished board or assembly process.

## Source and method

Source: the TPS7A8101 datasheet downloaded directly from TI, stored here as `TI-TPS7A8101-datasheet.pdf`. Pages 25–27 contain drawing **DRB0008A, 4218875/A (01/2018)**: package outline, example board layout and example stencil. Page 3 supplies the top-view pin mapping. Ordering information identifies TPS7A8101DRBR as the eight-lead DRB package. Verify the purchase order uses this exact part/package.

https://www.ti.com/lit/ds/symlink/tps7a8101.pdf?ts=1781253131486

I visually reviewed those drawings, loaded the saved `.kicad_mod` through KiCad's `pcbnew` library, checked its actual numerical pad geometry, and exported the six relevant layers through KiCad. `geometry-check-results.json` records passing checks and SHA-256 hashes of the footprint and source PDF. `check_footprint.py` is the reproducible geometry check.

## Comparison

All dimensions are millimeters. Coordinates below are relative to the footprint center, viewed from the top of the PCB, with positive Y downward.

| Feature | TI drawing | Corrected KiCad footprint | Result |
|---|---|---|---|
| Body outline | 3.0 × 3.0 nominal, 2.9–3.1 range | 3.0 × 3.0 fabrication outline | Match nominal |
| Lead pitch | 0.65 | 0.65 | Match |
| Opposite lead-pad center spacing | 2.8 | X = ±1.4 | Match |
| Lead copper pads | 0.6 × 0.31, R0.05 | 0.6 × 0.31, R0.05 | Match |
| Lead row positions | 1.95 span across four rows | Y = −0.975, −0.325, +0.325, +0.975 | Match |
| Central exposed-pad land | 1.5 × 1.75 | 1.5 × 1.75 | Match |
| Four narrow ground-land extensions | 0.23 wide; center spacing 0.65; outer ends 0.825 beyond first/last lead row | X = ±0.325; end Y = ±1.8 | Match |
| Central paste aperture | 1.34 × 1.55 | 1.34 × 1.55 | Match |
| Four paste extensions | 0.23 × 0.725; total end-to-end span 2.674 | X = ±0.325, Y = ±0.9745 | Match |
| Preferred non-solder-mask-defined opening | At least 0.07 outward clearance | Explicit +0.07 footprint mask margin | Matches nominal minimum |
| Lead paste | Same nominal aperture as lead land | Explicit zero additional shrink | Match |
| Pin numbering | Top PCB view: 1 upper left, down to 4 lower left; 5 lower right, up to 8 upper right | Same arrangement; exposed land uses pad 9 | Match |

The ground extensions overlap the central pad by 0.05 to form a continuous rounded copper shape. All five copper primitives are numbered **9** and therefore connect to the same ground net. Five paste-only primitives form the stencil opening; they are not extra electrical terminals. The central paste has no blanket full-pad opening added on top of it.

TI labels its example as 84% exposed-pad paste coverage for a 0.125 mm thick stencil. That percentage refers to its device/stencil design, not simply the area of our rectangular central copper land. The footprint adopts TI's aperture dimensions; the assembler must select stencil thickness and processing.

## Corrections made during this review

The original eight lead pads, numbering and central exposed-pad dimensions were correct. The original footprint omitted the narrow ground-land extensions and used four simple paste windows rather than TI's illustrated central aperture plus extensions. Those features were corrected. Explicit mask/paste overrides were added, the courtyard was enlarged to contain the extended copper and pin-1 marker, and silkscreen lines were split to avoid the extended mask openings. A chamfer was added to the fabrication outline at pin 1. The library filename and schematic footprint reference remain unchanged.

The pre-review version is retained as `original-footprint-before-review.txt` for audit only. Do not use it as a library footprint. The original generator was updated so a later regeneration will not restore the old geometry, but do not rerun that generator over hand-edited schematics.

## Inspection files and integration

- `FOOTPRINT_CHECK_ONLY.kicad_pcb`: a single-component inspection board; NOT the system PCB or a production layout.
- `FOOTPRINT_CHECK_ONLY.pdf`: six enlarged KiCad layer plots at 20× scale, NOT a 1:1 paper fit template.
- `kicad-layer-plots/`: SVG versions of copper, paste, mask, silkscreen, fabrication and courtyard.
- The PNG images are crops rendered from those actual KiCad-exported layer plots.

The corrected file is `../LDO_Power.pretty/TI_DRB0008A_VSON8_3x3mm.kicad_mod`. Any future placement from this library will use the corrected footprint. If a PCB already contains the old footprint, use **Tools → Update Footprints from Library** in PCB Editor, then inspect the updated copper, paste and mask. PCB footprints are stored as copies; editing the library alone does not update an existing placement.

The schematic's pin-to-function mapping was also checked: 1/2 OUT, 3 FB, 4 GND, 5 EN, 6 NR, 7/8 IN, exposed pad ground. Existing electrical netlist checks confirm these nets and the exposed pad connection.

## Remaining board-specific work

Thermal vias are not included automatically. TI provides optional example via locations; select via construction with the fabricator/assembler and avoid uncontrolled solder loss into open vias under paste. The system board still needs its ground copper, routing, thermal design, board-level DRC and final fabrication-output review. A 1 A LDO load can dissipate about 1.7 W. No thermal analysis or physical component-fit measurement was performed in this dimensional check.

The footprint has no 3D model; its absence does not change the copper pads. This verification establishes conformity with the cited nominal land pattern. Final assembly acceptance depends on fabrication tolerances, stencil/process choices and the exact part purchased.

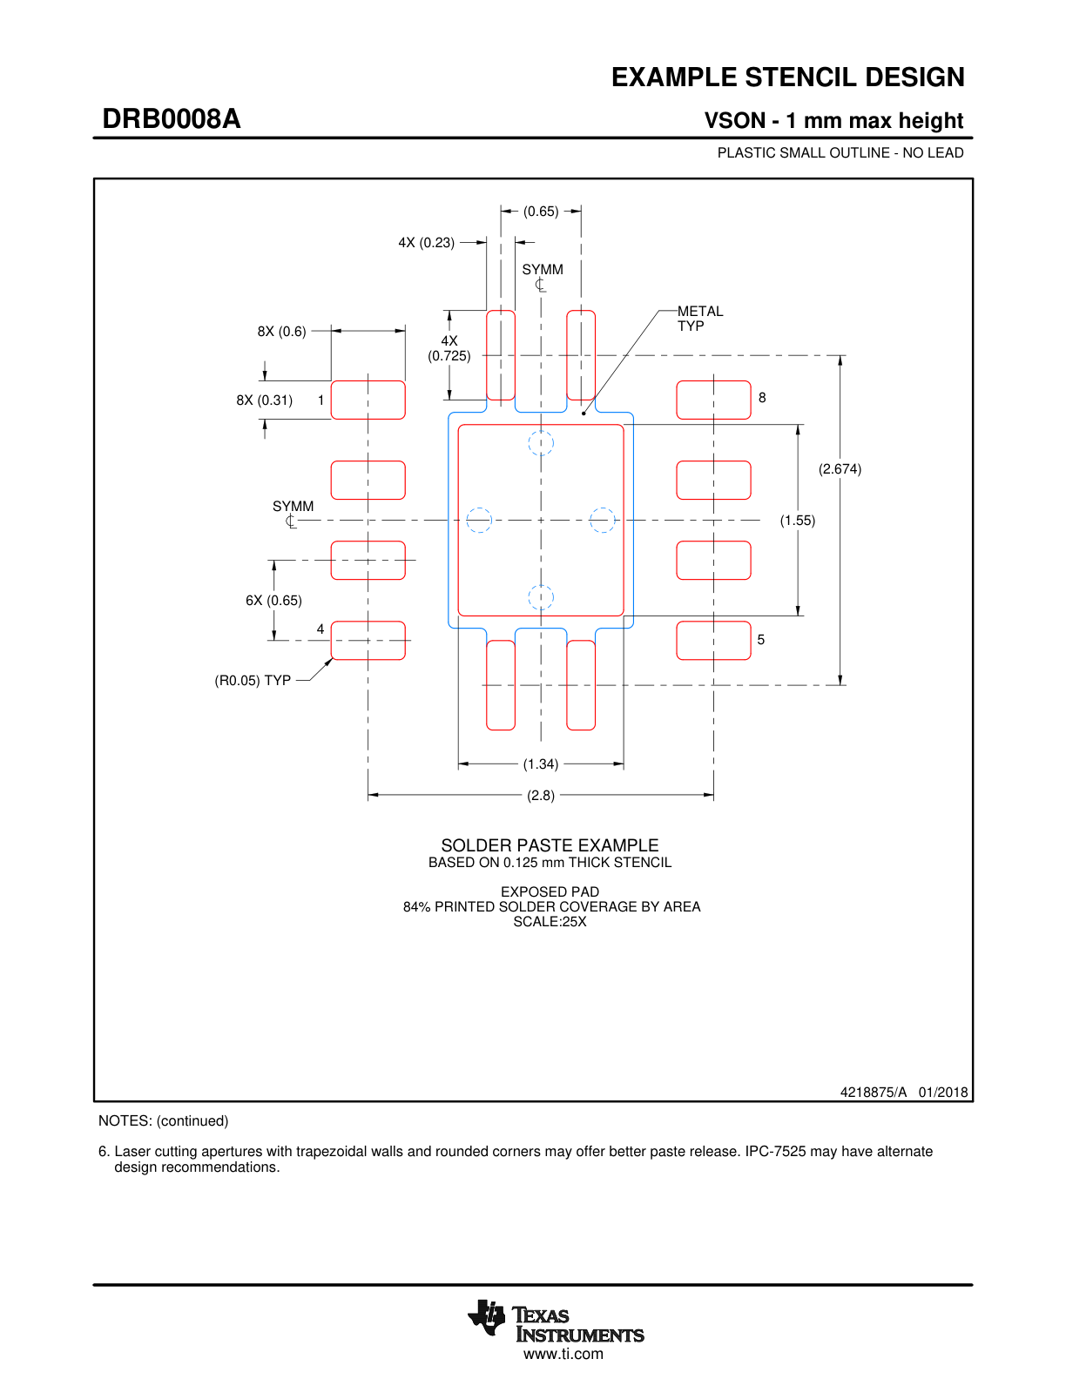
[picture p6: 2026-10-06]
LDO_KiCad/footprint-verification/TI-page-27.png

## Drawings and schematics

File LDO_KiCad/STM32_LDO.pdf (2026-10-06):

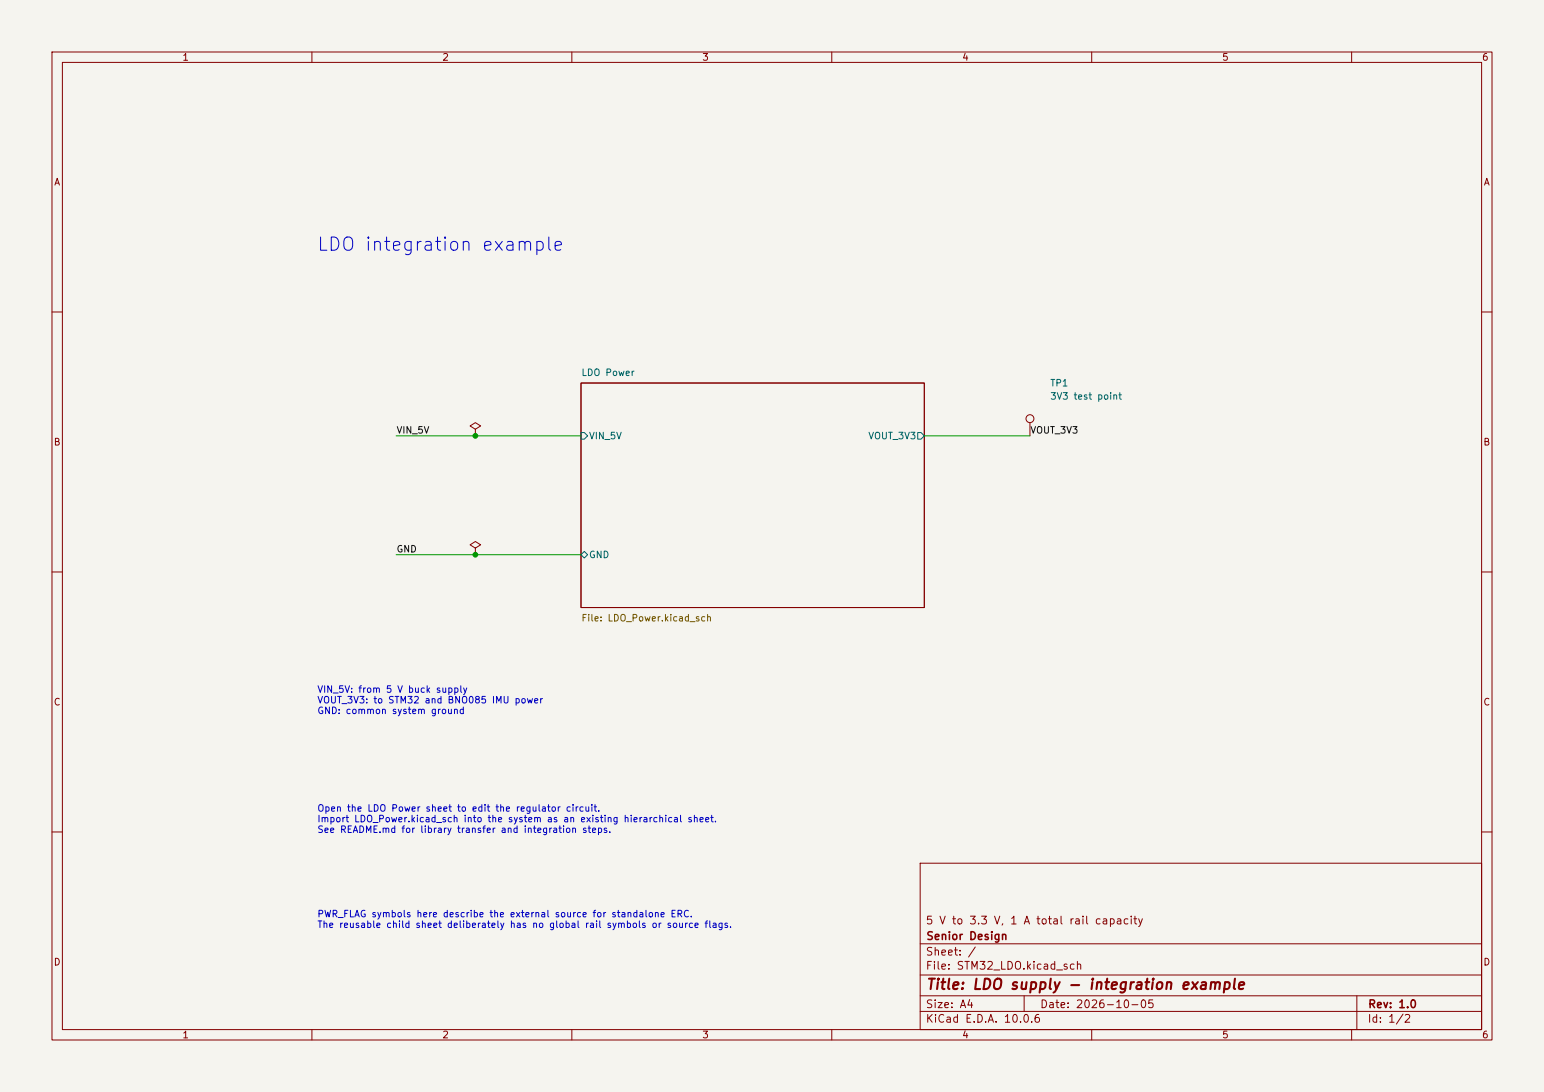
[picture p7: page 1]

PWR_FLAG symbols here describe the external source for standalone ERC. The reusable child sheet deliberately has no global rail symbols or source flags. VIN_5V: from 5 V buck supply VOUT_3V3: to STM32 and BNO085 IMU power GND: common system ground

Open the LDO Power sheet to edit the regulator circuit.
Import LDO_Power.kicad_sch into the system as an existing hierarchical sheet. See README.md for library transfer and integration steps.

5 V to 3.3 V, 1 A total rail capacity
Senior Design
Sheet: /
File: STM32_LDO.kicad_sch
Title: LDO supply - integration example

Size: A4 | Rev: 1.0
KiCad E.D.A. 10.0.6 | Id: 1/2

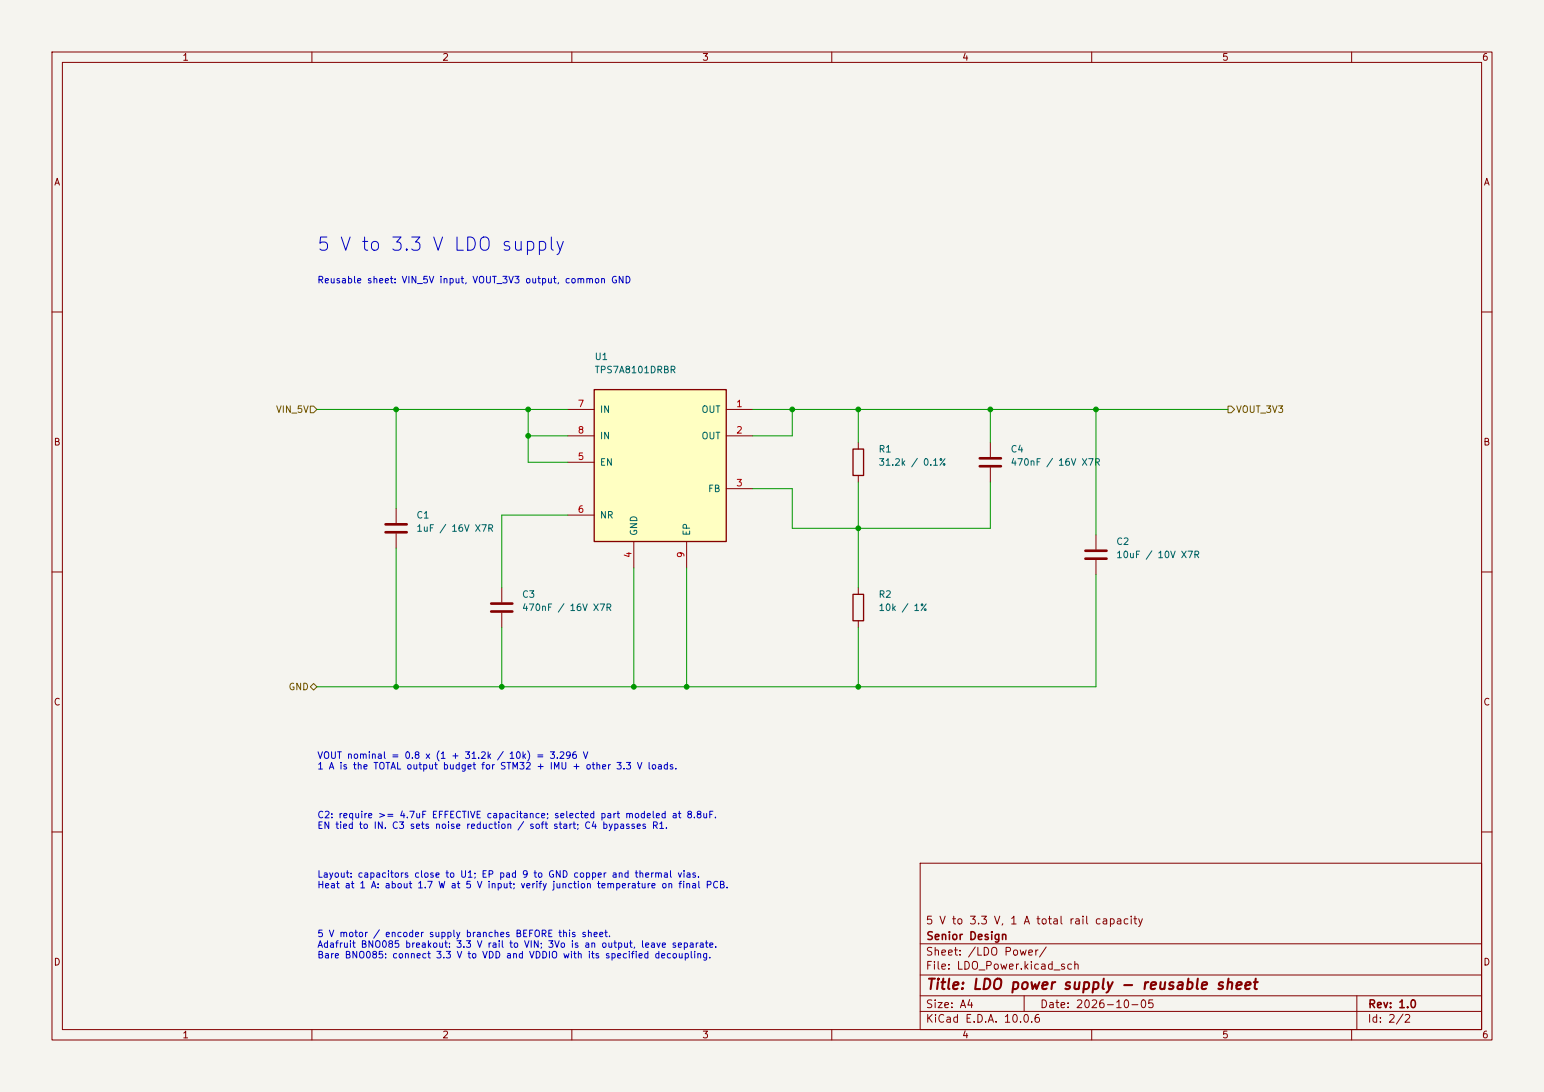
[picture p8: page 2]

5 V motor / encoder supply branches BEFORE this sheet. Adafruit BNO085 breakout: 3.3 V rail to VIN; 3Vo is an output, leave separate. Bare BNO085: connect 3.3 V to VDD and VDDIO with its specified decoupling. VOUT nominal = 0.8 x (1 + 31.2k / 10k) = 3.296 V 1 A is the TOTAL output budget for STM32 + IMU + other 3.3 V loads. Layout: capacitors close to U1; EP pad 9 to GND copper and thermal vias. Heat at 1 A: about 1.7 W at 5 V input; verify junction temperature on final PCB. C2: require >= 4.7uF EFFECTIVE capacitance; selected part modeled at 8.8uF. EN tied to IN. C3 sets noise reduction / soft start; C4 bypasses R1. 5 V to 3.3 V LDO supply

Reusable sheet: VIN_5V input, VOUT_3V3 output, common GND

5 V to 3.3 V, 1 A total rail capacity R2

Senior Design
Sheet: /LDO Power/
File: LDO_Power.kicad_sch
Title: LDO power supply - reusable sheet

Size: A4 | Rev: 1.0
KiCad E.D.A. 10.0.6 | Id: 2/2

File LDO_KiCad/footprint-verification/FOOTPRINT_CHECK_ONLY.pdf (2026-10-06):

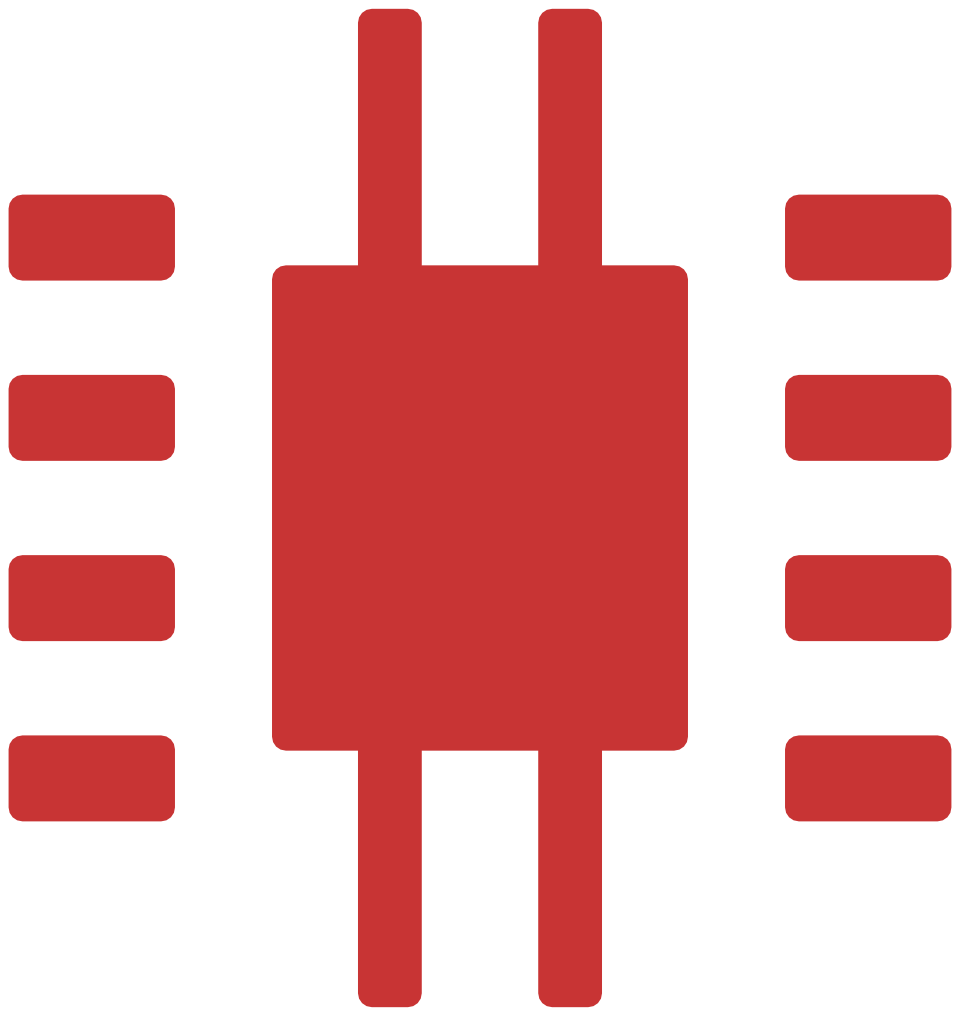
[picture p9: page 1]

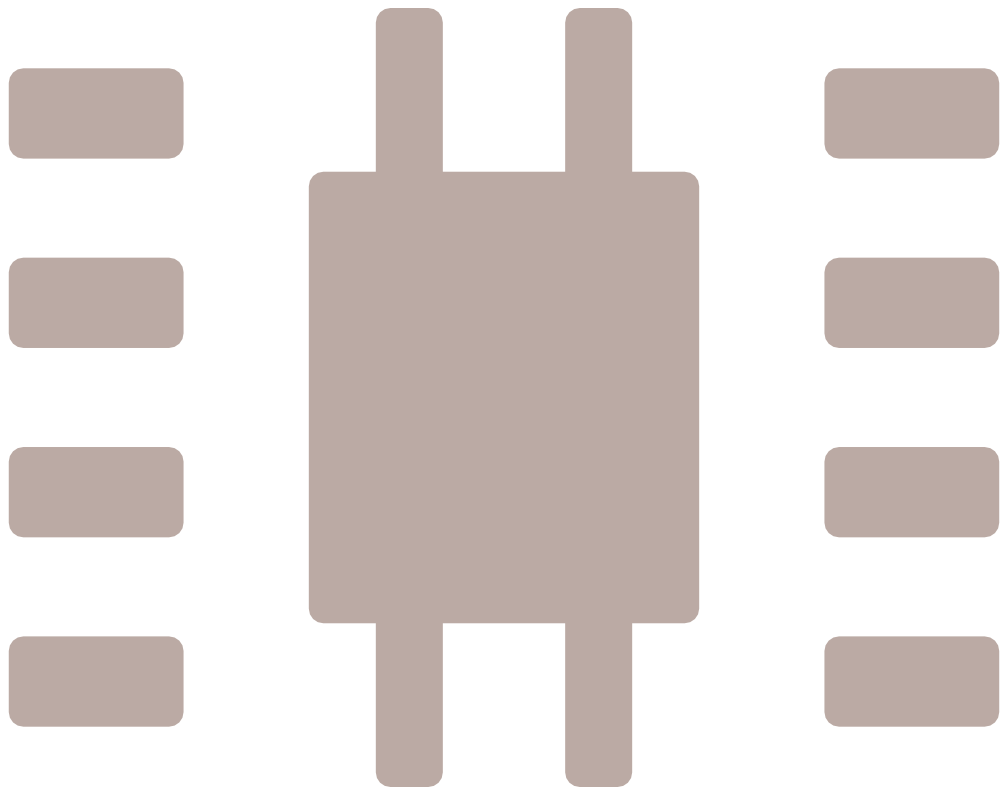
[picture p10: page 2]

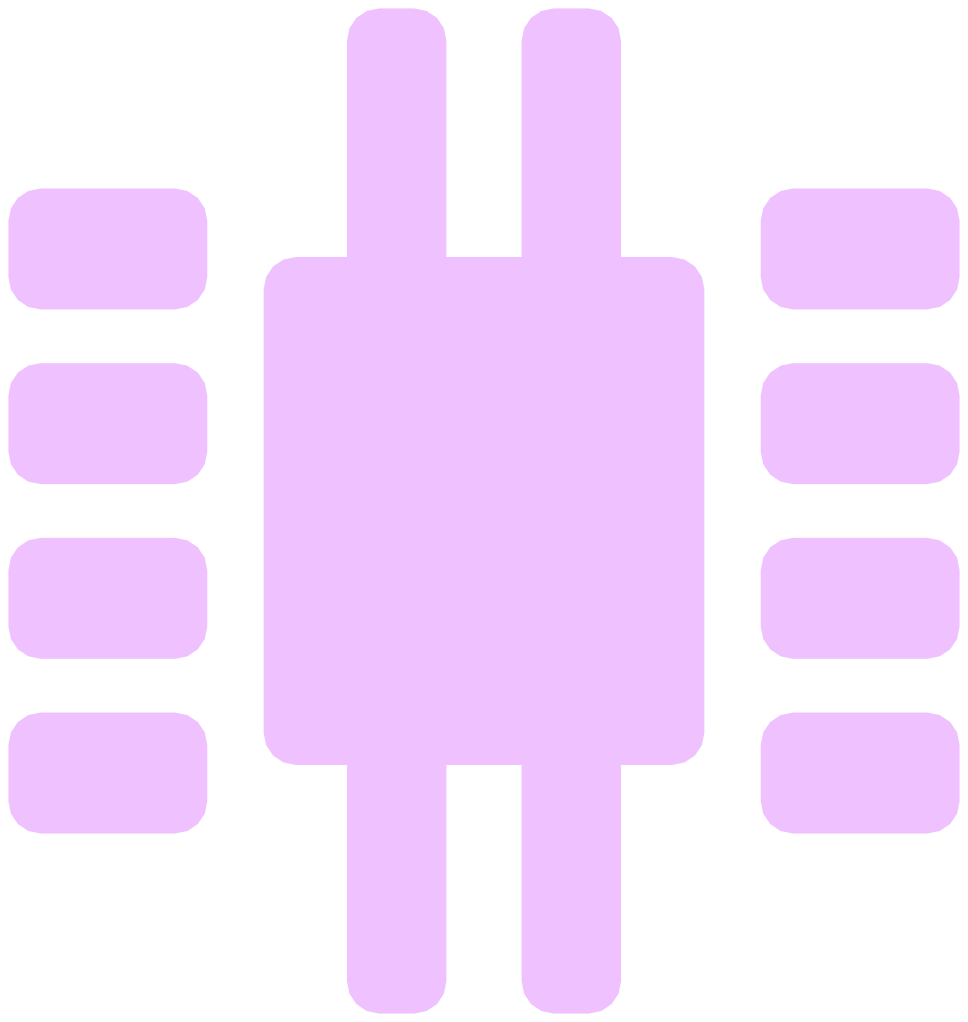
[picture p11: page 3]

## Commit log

2026-10-06 Initialize PCB workspace with verified LDO module and pending system schematic
    [FOOTPRINT_CHECK_ONLY.kicad_pcb, LDO_Power.kicad_sch, STM32_LDO.kicad_sch]
2026-10-06 Integrate 3.3 V LDO with selected 2 A buck rail and STM32 supply
    [LDO_3V3.kicad_sch, delivery_robot_1.kicad_sch]
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2026-10-06 Connect TPSM63606 analog ground to power ground per TI datasheet
    Join U2's previously isolated AGND net to the system GND/PGND net.
    AGND pins 6 and 11 now share the ground reference with PGND pins
    17-20, the R2 frequency-setting resistor return, and the R5 feedback
    divider return. This prevents the regulator's analog reference from
    floating relative to its power stage and external setting resistors.
    Reference: TI TPSM63606 datasheet, SLVSGB4B, Rev. B (April 2022),
    Table 6-1, page 4: AGND must connect to PGND; RT and the lower feedback
    resistor return to AGND. Section 11.1, page 31, specifies connecting
    AGND pins 6 and 11 directly to PGND pin 19 under the module.
    https://www.ti.com/lit/ds/sy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
    [delivery_robot_1.kicad_sch]
2026-10-06 Connect TP1 to the 5 V, 2 A buck output net
    Rename the power symbol attached to TP1 from +5V to +5V, 2A so the
    connection point belongs to the TPS54202 output after L1. Previously,
    +5V was a separate net containing only TP1 and did not connect to
    either buck output. This makes TP1 usable for accessing the intended
    2 A supply and keeps the 6 A supply electrically separate.
    Validation: exported the saved schematic using KiCad 10.0.6 and
    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
    [delivery_robot_1.kicad_sch]
2026-10-06 Standardize every resistor footprint to the required 0805 package
    Assign Resistor_SMD:R_0805_2012Metric to all system resistors R1-R9
    and both resistors in the reusable LDO schematic. This meets the
    team's requirement that every resistor use 0805, fills the five
    missing system resistor footprints, and replaces existing 0603
    assignments. Document the requirement and remaining part-rating checks.
    Validation: the installed KiCad 0805 footprint exists. Exported
    before/after system netlists confirm all nine resistor footprints are
    0805 and every component value and electrical net connection is
    unchanged. Resistance tolerances are preserved. git diff --check passed.
    Purchasing parts must still m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
    [LDO_3V3.kicad_sch, LDO_Power.kicad_sch, delivery_robot_1.kicad_sch]
2026-10-06 Select datasheet-backed power capacitors and inductor footprints
    Assign the ten missing buck capacitor footprints and L1, with actual
    manufacturer part numbers, ratings and source links. Select 1210
    Murata capacitors for the TPSM63606 input/output banks, 0603 ceramics
    for bypass/bootstrap/feedforward roles, and a 50 V TDK 2220 part for
    the existing 22 uF TPS54202 input capacitor. Keep all capacitances.
    Complete LDO noise/bypass capacitor part numbers and replace the input
    capacitor ordering number with a matching 1 uF 16 V 0603 Murata part;
    keep the reusable LDO example consistent.
    Change L1 from 10 uH to 15 uH and select Coilcraft XAL6060-153MEC.
    At 2 A output, 28 V input, 390 kHz and -20%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
    [LDO_3V3.kicad_sch, LDO_Power.kicad_sch, delivery_robot_1.kicad_sch]
2026-10-06 Select optional STM32 HSE crystal and matching load capacitors
    Specify Y3 as Abracon ABM3B-8.000MHZ-B2-T and C5/C6 as Murata
    GRM1885C1H160JA01D (16 pF, 50 V, C0G, 5%). Retain DNP on all three
    so initial assembly can use the MCU internal clock while preserving
    pads and purchasing information for a later external-clock option.
    STM32F091xB/xC datasheet DocID026284 Rev 4, p69 Table 39, permits
    8 MHz HSE and gives 10 mA/V minimum startup transconductance. Its
    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
    [delivery_robot_1.kicad_sch]
2026-10-06 Select replaceable 7.5 A battery-input fuse and verified MINI holder
    Specify F1 as a Keystone 3568 PCB holder with a Littelfuse 029707.5L
    7.5 A, 32 VDC MINI insert. Both bucks share this input branch: their
    5 V/6 A and 5 V/2 A outputs total 40 W. At the battery's 10.8 V minimum
    normal voltage and an assumed 85% efficiency, estimated input current
    is 4.36 A. The LDO load is already included in the 2 A branch.
    Littelfuse MINI 32 V datasheet (2024-09-27), p3, allows 6.0 A at 40 C
    for the 7.5 A fuse versus 4.0 A for the 5 A fuse. This makes 7.5 A the
    lowest standard option above the estimated continuous full-load current
    at the team's 40 C ambient limit. Pages 1-2 specify 32 VDC operation
    and 1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
    [delivery_robot_1.kicad_sch]
2026-10-06 Move both buck converters onto hierarchical sheets
    Split the TPS54202 (U3) and TPSM63606 (U2) circuits out of the root
    schematic into Buck_5V_2A and Buck_5V_6A child sheets, wired like the
    LDO sheet with VIN_12V, GND and VOUT_5V hierarchical labels connected
    to +12V, GND, +5V 2A and +5V 6A in the root. Net connectivity is
    unchanged except the redundant GNDA symbol on U2 is dropped.
    Add datasheet, product page, key specs and design notes to U2 and U3,
    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
2026-10-06 Add motor 1 driver and encoder screw terminals
    Label the STM32 pins used in the motor prototype: PA6 MOTOR1_PWM
    (TIM3_CH1 to DRI0002 E1), PB0 MOTOR1_DIR (M1), PA15 ENC1_A and PB3
    ENC1_B (TIM2 encoder inputs).
    Add screw terminals to the right of U1:
    - J6, 3-pos: MOTOR1_PWM, MOTOR1_DIR, GND for the DFRobot DRI0002
    - J7, 4-pos: +5V 2A, ENC1_A, ENC1_B, GND for the 37D motor encoder
    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
2026-10-06 Add GPIO breakout headers and make MCU labels global
    Convert every local net label on the STM32 pins to a bidirectional
    global label so the signals can be referenced from any sheet.
    Add 2.54 mm male pin headers to the right of U1 that break out all
    43 otherwise unused MCU pins, each ending in a GND pin:
    - J8 (1x13): port A - PA0-PA4 incl. USART2_TX/RX, LED_USER, PA7-PA12
    - J9 (1x15): port B - PB1, PB2, PB4-PB15
    - J10 (1x18): ports C/D - PC0-PC12, USER_BTN, OSC32_IN/OUT, PD2
    Footprints: Connector_PinHeader_2.54mm PinHeader_1xNN_P2.54mm_Vertical.
    Motor, SWD, reset, boot and HSE crystal pins stay on their existing
    connections.
2026-10-06 Rearrange root schematic layout
    Reposition the MCU, motor terminals, GPIO breakout headers and
    supporting circuitry on the root sheet for readability. Layout only:
    the exported netlist is identical to the previous commit (75 nets,
    same pin groupings) and ERC results are unchanged.
2026-10-06 Add off-board BNO085 IMU connectors on I2C1
    Connect an off-board BNO085 breakout (Adafruit 4754 / SparkFun style):
    - J11: JST SH 4-pin SM04B-SRSS-TB in STEMMA QT / Qwiic order
    (1 GND, 2 +3V3, 3 SDA, 4 SCL), powered from the 3.3 V LDO rail,
    mounting pads to GND
    - J12: 2.54 mm 2-pin header for the IMU INT and RST lines
    - R10/R11: 4.7k 0805 SDA/SCL pull-ups to +3V3, marked DNP since the
    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
2026-10-06 Add Raspberry Pi 5 UART screw terminal on USART2
    Add a 3-wire UART link to the Pi 5 GPIO header:
    - J13: Phoenix MKDS 1,5/3 5.0 mm screw terminal (1715035)
    1 = PI_TXD from Pi GPIO14 TXD (header pin 8)
    2 = PI_RXD to Pi GPIO15 RXD (header pin 10)
    3 = GND (Pi header pin 6)
    - R12/R13: 100R 0805 series resistors between USART2_TX (PA2) /
    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
2026-10-06 Add fused, isolatable Pi 5 power output from the 6 A buck
    Feed the off-board Raspberry Pi 5 from the +5V, 6A buck rail:
    - F2: Keystone 3568 MINI holder with Littelfuse 029707.5L 7.5 A fuse,
    same verified parts as F1. Pulling the fuse isolates the Pi so the
    buck can be checked and load-tested first; fitted, it protects the
    Pi cable (6.0 A allowed at 40 C, above the Pi 5's 5 A maximum).
    - J14: Phoenix MKDS 1,5/2 5.0 mm screw terminal (1715022, 17.5 A,
    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
2026-10-06 Switch motor 1 driver notes from DFRobot DRI0002 to Cytron MDD20A
    The Cytron MDD20A (20 A, 6-30 V, 2-channel) uses the same control
    interface as the DRI0002 on channel 1, so J6 wiring is unchanged:
    1 = PWM1 (PA6, TIM3_CH1), 2 = DIR1 (PB0), 3 = GND. Its logic
    thresholds (low <= 0.8 V, high >= 1.5 V) accept the STM32's 3.3 V
    outputs; keep PWM at or below 20 kHz.
    Update J6's value and description and the motor section note,
    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
2026-10-07 Add second 6 A buck and split Pi and GPIO blocks into sheets
    Duplicate the 12 V to 5 V, 6 A TPSM63606 buck as an independent
    sheet (Buck_5V_6A_AUX, U5, C28-C33, R14-R16) and rename the two
    outputs so they can't be confused:
    - +5V, 6A PI: the existing buck (U2), feeding the Pi 5 via F2/J14
    - +5V, 6A AUX: the new buck (U5), no loads assigned yet
    Move the Raspberry Pi 5 UART (J13, R12/R13) and power output
    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
2026-10-07 Add schematic PDF and pre-commit hook that keeps it current
    Add delivery_robot_1.pdf, a KiCad plot of all 7 schematic sheets.
    Add tools/hooks/pre-commit: when a commit includes .kicad_sch or
    .kicad_pro changes, it plots the PDF with kicad-cli from the staged
    files (a checkout-index snapshot, so it matches exactly what is
    committed) and adds it to the same commit. It aborts the commit if
    kicad-cli is missing or the export fails, so the PDF never silently
    goes stale. Enable per clone with:
    git config core.hooksPath tools/hooks
    Document the PDF, the hook and the setup step in the README.
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2026-10-08 Consolidate power test points into one header on a Test Points sheet
    New Test_Points.kicad_sch sheet (page 10) replaces the root sheet's
    3-pin J5 with a single, power-only test header:
    - J5: 1x06 2.54 mm male header, ordered by voltage:
    1 GND, 2 +3V3, 3 +3.3VA, 4 +5V 2A, 5 +5V 6A AUX, 6 +12V (after F1)
    - TP3: Keystone 5011 black multipurpose GND loop for a scope ground clip
    +5V 6A PI stays on TP1 on the Pi 5 Interface sheet, which the Pi
    bring-up steps use. The root keeps a Test Points sheet block where J5
    was.
    Includes manual layout edits made in KiCad: TP3 note repositioned on
    the Test Points sheet, plus KiCad re-saving the Motor Control and
    Power Indicators sheets (formatting only, no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
2026-10-08 Add +12V bulk capacitor, document XT30 polarity decision, use E96 values
    Input (sheet 1, near J2):
    - C36: 220 uF / 35 V low-ESR electrolytic (Panasonic EEU-FR1V221,
    8 x 11.5 mm radial) on +12V right after F1.
    - Reverse polarity: no P-FET; rely on the keyed XT30. Note on sheet 1
    and in docs/power-supply.md: the housing cannot mate reversed, but a
    harness crimped backwards at the battery lugs is not caught (it would
    reverse-bias both bucks and C36 until F1 blows), so meter-check harness
    polarity before first power-up and after rework.
    All resistor values are now E96:
    - R4 40k -> 41.2k 1%: Pi rail 5.12 V (5.1 V target)
    - R15 40k -> 40.2k 1%: AUX rail 5.02 V
    - R8/R9 31.2k/10k -> 35.7k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
2026-10-08 Rename power nets, add mounting holes, retitle sheet 1, clear ERC
    Power nets, no commas, named by function:
    - "+5V, 2A" -> +5V_SYS, "+5V, 6A PI" -> +5V_PI, "+5V, 6A AUX" -> +5V_AUX
    Buck sheets renamed to Buck 5V SYS / Buck 5V PI / Buck 5V AUX. Notes,
    descriptions, README and docs updated.
    Mechanical and title:
    - H1-H4: M3 mounting holes, 3.2 mm plated, isolated (no net), not in BOM
    - Sheet 1 title: "Delivery Robot Main Board"
    ERC, now 0 errors and 0 warnings (was 4 errors, 15 warnings):
    - PWR_FLAGs on +12V (after F1), GND (at J2), +3.3VA (after FB2) and
    +5V_SYS (after the TPS54202's L1)
    - TPSM63606 symbol pin types set (VOUT power out, FB/EN input, VIN/
    VLDOIN/GND power in, PG open col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
2026-10-14 Start PCB layout: place and lock M3 mounting holes with keepouts
    Add delivery_robot_1.kicad_pcb (80 x 90 mm outline, 4-layer stackup
    with In1.Cu GND and In2.Cu PWR, all footprints imported).
    Mounting holes H1-H4, 4 mm in from each corner of the outline (top-left
    corner at 85, 50 mm):
    H1 (4, 4) H2 (76, 4) H3 (4, 86) H4 (76, 86) mm
    - Footprint changed to MountingHole_3.2mm_M3: non-plated (NPTH), no
    copper ring, no pad number. Updated in the schematic and swapped in
    place on the board; DRC schematic parity is clean.
    - All four footprints locked.
    - A 7 x 7 mm keepout rule area centred on each hole on F.Cu, In1.Cu,
    In2.Cu and B.Cu: no tracks, vias or copper fills; pads and footprin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
2026-10-14 Grow board to 100 x 100 mm and place power input, motor I/O and ESD
    Board outline 80 x 90 -> 100 x 100 mm (top-left corner fixed at 85, 50),
    bringing part area from ~47 % to ~33 % of the usable board. Holes stay
    4 mm in from each corner, locked, each with its 7 x 7 mm keepout:
    H1 (4,4), H2 (96,4), H3 (4,96), H4 (96,96). The unplaced parts were
    shifted 25 mm right to clear the new outline.
    Power input, top-left, as a straight path J2+ -> F1 -> C36:
    - J2 XT30: rotated 180 deg so the plug opening faces the left edge
    (it was facing into the board); front 0.5 mm in from the edge
    - F1 fuse holder next to J2's + pin; C36 220 uF right after F1's +12V
    Motor I/O, bottom-right corner (wire entries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
2026-10-14 Remove the IMU from the board; it will be wired off-board
    The BNO085 IMU is now connected discretely off the PCB, so everything
    for it is removed from the schematic and the layout:
    - Delete the IMU Interface sheet (IMU_Interface.kicad_sch): J11 STEMMA
    QT connector, J12 INT/RST header, DNP I2C pull-ups R10/R11 and series
    resistors R34/R35; remove its sheet block, note and project entry
    - Remove debug LED D10 / R23 (LED_IMU on PB13)
    - Rename the freed MCU nets back to plain pins, still broken out on the
    GPIO headers: IMU_SCL -> PB6, IMU_SDA -> PB7 (J9), IMU_INT -> PC4,
    IMU_RST -> PC5 (J10), LED_IMU -> PB13 (J9)
    - Drop IMU wiring notes and the IMU 3.3 V budget line from the LDO sheet;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
2026-10-15 Place LED and resistor groups, route 3.3 V rails, relabel LEDs
    - Place D5, TP3, UART series resistors R12/R13 and resistors R3,
    R17-R22, R24 and R26-R33.
    - Move C1, and the motor-side regulators U6/U7 with C34/C35.
    - Route +3V3, +3.3VA, BOOT and GND tracks; add one copper zone.
    - Rename the power/status LED references to rail names
    (D3 -> 3V3, D4 -> 12V, D6 -> AUX, D7 -> SYS, D8 -> HB, D9 -> PI,
    D11 -> MOT). These no longer match the schematic references.
    - Unlock the previously locked placements for rework.
    Schematic:
    - Shorten the J13 note in Pi5_Interface (drop the Pi header pin
    numbers for TXD/RXD).
    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
2026-10-15 Fix the TPSM63606 footprint in the project library
    The RDL0020A-MFG footprint caused 40 DRC errors on the board (16 drill,
    16 solder-mask bridge, 8 clearance), all from its 8 thermal vias. Earlier
    fixes were made on the board copies only, so "Update footprints from
    library" would have undone them. Fixed in the library instead:
    - Number each via as the PGND pad it sits in (21,22 -> 19; 23,24 -> 18;
    25,26 -> 20; 27,28 -> 17), so the vias are GND rather than netless.
    - Drill 0.2032 -> 0.3 mm on a 0.6 mm pad (fab minimum; TI asks for
    0.3 mm vias into the GND planes), tented on the bottom, and a solid
    zone connection so PTH thermal reliefs never apply to them.
    - Add the F.CrtYd courtyard (s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
2026-10-15 Add input protection, AUX ports, servo interface and Pi control
    Implements the 2026-10-15 design review decisions in the schematic.
    ERC 0 errors, 0 warnings.
    New sheets:
    - Input Protection: Q1 SQJ409EP reverse-battery P-FET after F1 (D12
    12 V gate clamp, R36), D13 SMBJ16A TVS on +12V, battery sense
    R37/R38/C37 -> VBAT_SENSE on PA0. PWR_FLAG moves to +12V.
    - AUX Outputs: four +5V_AUX ports J18-J21 (JST XH 2-pin: Notecard,
    LiDAR, GNSS, IMU), each through a 1.5 A PTC (F4-F7).
    - Servo Interface: J17 (GND, VBAT_SERVO via F3 5 A fuse, SERVO_SIG) for
    the Hiwonder HTS-30HS through an external 11.1-12 V buck. U8
    SN74LVC1T45 translates PB10 (USART3 half-duplex) to the 5 V bus,
    PB11 sets d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
2026-10-15 Update the board from the schematic and place the new parts
    As Update PCB from Schematic, on top of c692e23: 61 footprints added,
    J8/J9/J13 swapped to their new footprints, U2/U5 refreshed from the
    fixed library footprint, TP2 deleted, pad nets updated. Every existing
    track and via is unchanged (87 items, identical), and Venya's latest
    placement (LEDs, R12/R13, R26-R33, U6/U7, C34/C35, TP3) is kept.
    Schematic parity: the seven LEDs renamed on the board (3V3, 12V, AUX,
    SYS, HB, PI, MOT) get their schematic references back (D3, D4, D6, D7,
    D8, D9, D11). Their rail names stay on the silkscreen as plain text in
    the same spot, and the references move to the fab layer, so the board
    looks the same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
2026-10-15 Document the 2026-10-15 design review changes
    - docs/design-review-2026-10-15.md: what changed and why, new MCU pin
    jobs for firmware, the remaining layout work in order, a bring-up
    checklist and the verified part numbers.
    - power-supply.md: input chain with Q1/D13, battery sense, AUX enable,
    harness fuse 15 A; resolve the old open items (VCC must stay NC,
    floating TPS54202 EN is allowed, C26/C27 start-up).
    - fuse-selection.md/.json: F1 10 A sizing with the AUX and servo loads,
    plus a table of the other fuses and PTCs (F3-F11).
    - README: new sheets, updated sheet descriptions and design status.
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2026-10-15 Switch AUX ports to top-entry JST XH; drop encoder pull-ups and Pi sense
    - J18-J21 (peripheral 5 V ports) are now top-entry JST XH B2B-XH-A:
    cables plug in from above, which suits a flat board you reach into,
    and the footprint drops from 107 to 58 mm2 per port. Use pre-made
    2-pin XH cables, so no crimping.
    - Remove the DNP encoder pull-ups R48-R51. If the am-3651 outputs turn
    out to be open-collector, bodge 4.7k from each A/B line to ENCn_5V
    (noted on the Motor Control sheet).
    - Remove the Pi-alive sense R44/R45. PA1 is a spare pin again (J8 pin
    2); the Pi's 3V3 on J13 still enables the AUX buck through D15.
    - Board: same edits as Update PCB from Schematic (J18-J21 swapped,
    six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
2026-10-18 Place input protection and start AUX/servo placement
    - Place the input protection parts beside J2/F1: Q1, D12, D13, R36.
    - Place C37, C49 and R37/R38, and move C1 to fit.
    - Park the AUX/servo parts (J22, Q2, D15, C40, R43, R46, R47) left of
    the board outline ready for placement.
    - Rework +3V3/GND routing around the new parts (2 +3V3 segments
    removed, 3 GND tracks and 3 GND vias added).
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2026-10-20 Route the board and apply the prototype PCB checklist fixes
    Routing
    - Route power (pours, In2 power areas, vias) and all signals; add a
    Signal net class (0.15 mm width/clearance) for low-speed nets.
    - J8 expansion header is now a 2x8 near the MCU.
    Checklist red flags
    - Crystal Y3 moved beside U1's OSC pins with C5/C6 outboard and no
    other signals under it.
    - Vias untented by default (tented only under silkscreen); 15 mil
    test vias on key signals, recorded as DRC exclusions.
    - ESD: U6/U7 split into four USBLC6-2SC6 (U6, U11, U7, U12), one per
    connector, with VBUS caps C50/C51; R12/R13 moved next to J13.
    - GND test loop TP3 moved to the top edge beside J5.
    Improvements
    - Encoder conn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
2026-10-20 Add outer-layer GND pours and stitching vias
    - Board-wide GND pours on F.Cu and B.Cu at lowest priority (0.5 mm
    clearance, solid SMD / thermal THT connections, island removal).
    - H5 copper keepout matching H1-H4; drop three redundant small F.Cu
    GND pours now covered by the full pour.
    - GND straps on J8 pin 16 and J5 pin 2 to fix starved thermals.
    - 165 GND stitching vias (6 mm grid, 5 mm edge row), kept clear of
    part bodies and silkscreen.
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2026-10-26 Apply TA layout feedback on regulator copper and In2
    - Add 13 vias on U2's +5V_PI output (next to VOUT pins and C11/C12)
    into a new In2 +5V_PI area that mirrors the top pour.
    - Mirror the regulator pours on In2: +12V under the input pours, GND
    under each module and its cap loops; add 15 +12V vias near
    C7/C8, C28/C29 and along the U5 feed.
    - Fix the 12V choke points: In2 +12V neck at x=121 widened from
    1.5 to 7 mm; the top-layer feed to U5 widened from 3.5 to 4.7 mm
    with a 6.5 mm In2 path in parallel.
    - Backfill In2 with a lowest-priority GND pour (62% -> 81% copper).
    - Include the U2/U5 tented GND vias added earlier.
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2026-10-27 Replace out-of-stock buck converters with in-stock TI parts
    TPSM63606 (U2, U5) and TPS54202 (U3) are out of stock at DigiKey.
    - U2 (Pi 5 V) and U5 (AUX 5 V), 6 A: TPS56637RPAR with Wurth
    74439387033 3.3 uH, 2x 10 uF + 100 nF in, 47 uF out, 73.2k/10k
    feedback with 20k + 100 pF feed-forward, 100k PG pull-up. Values
    from TI WEBENCH (10-15 V in, 5 V 6 A); load-step sim 0.6->6 A
    stays within 4.91-5.06 V.
    - U3 (+5V_SYS), 2 A: TPS54202HDDCR with TDK VLS6045EX-100M 10 uH,
    22 uF in, 47 uF out, 100k/13.7k + 68 pF, and a new 442k EN pull-up
    (R63) since the H version's EN is pulled down internally. Load-step
    sim 0.2->2 A stays within 4.72-5.21 V.
    - New TPS56637 symbol, RPA0010A footprint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
2026-10-27 Document the replacement buck converters
    README and power-supply.md now list TPS56637 (U2, U5) and TPS54202H
    (U3). New design-change note records the parts, DigiKey stock,
    WEBENCH simulations, deviations from the WEBENCH BOM and the
    datasheet-based layout. The old passive review is marked superseded
    for the bucks.
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2026-10-28 Remove right and acute track angles
    Chamfer 33 right-angle bends to 45 deg, turn 10 mid-track branches
    (including the +5V_AUX port taps) into Y joins with obtuse angles, and
    fix the four pad/via corners whose angle showed outside the copper.
    Remove 9 duplicate/overlapping segments and two dead-end stubs (PC0,
    AUX_EN). Only the U3 SW via fan, under its SW pour, keeps acute track
    angles. DRC: 0 violations, 0 unconnected, parity 0.
2026-10-28 Enlarge vias to 15.7 mil holes for flywiring
    All vias now have a 0.4 mm (15.7 mil) drill, above the 15 mil minimum
    needed to solder 28 AWG rework wire. Former 0.3/0.6 mm vias are
    0.4/0.66 mm (0.13 mm annular ring). Vias that no longer fit were
    nudged, and 17 signal nets around U1 and J8 were rerouted. The
    netclass via sizes, via preset and DRC minimums are raised to match
    so new vias cannot be undersized.
    DRC: 0 violations, 0 unconnected, 0 parity issues.
2026-10-28 Swap U13 to INA237 and set the Pi rail to 5.10 V
    U13: INA228AIDGSR -> INA237AIDGSR. The INA228 is out of stock at TI,
    LCSC and Mouser (next Mouser stock May 2027), and the INA238 is out
    too. The INA237 has the same VSSOP-10 pinout, -0.3 V to 85 V common
    mode, 0x40 address and +/-163.84 mV range, and Mouser stocks it. U13
    keeps the Sensor_Energy:INA228 symbol (identical pins); only Value,
    MPN, Datasheet and Description change, in the schematic and on the
    board. It is 16-bit and has no CHARGE register, so firmware now
    integrates current; the design-change doc has the new SHUNT_CAL
    (819.2e6 x 4 mA x 1.5 mOhm = 4915) and accuracy budget.
    R4: 73.2k -> 75k (RC0805FR-0775KL). +5V_PI = 0.6 V x (1 +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
2026-10-29 Apply TA layout review: vias off pads, obtuse corners, buck layouts
    - Move every via off its pad. The +3V3 vias at U6/U11/C34/C50 sit
    0.03-0.06 mm from the pad edge, without overlap, and are tented.
    - Remove the remaining acute and right-angle track corners, including
    where tracks leave a pad, and straighten small jogs (R27 pin 2).
    - U2/U5: add a second 47 uF output cap (C57, C58) to match the
    two-Cout datasheet layout, and add more PGND vias. F1 moves up 1 mm
    to make room for C57.
    - U3: move C14 down 1 mm so the input cap GND pads have a via on each
    side.
    DRC: 0 violations, 0 unconnected, 0 parity issues. ERC clean.
